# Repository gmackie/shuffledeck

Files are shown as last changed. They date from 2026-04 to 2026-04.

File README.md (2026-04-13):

# ShuffleDeck

Open-source automatic card shuffler for poker tables. Casino-grade randomization at a fraction of the cost.

## What is this?

A table-installed automatic shuffler that produces mathematically verified random output (9.2 riffle equivalents, indistinguishable from true uniform). Plus an RFID hole card reader and streaming overlay for live poker broadcasts.

## Product line

| Product | Price | Status |
|---|---|---|
| **ShuffleDeck Core** | ~$500 kit | CAD + firmware complete, pre-physical-build |
| **ShuffleDeck RFID** | ~$300 add-on | Prototype firmware, needs hardware validation |
| **ShuffleDeck Stream** | Free | Working demo overlay |

## Architecture

2-pass, 8-bin random FIFO shuffle. 52 cards are singulated by a friction roller, routed to one of 8 bins by a belt-driven selector, recombined, and shuffled again. The result is mathematically indistinguishable from a true uniform random permutation.

- **Shuffle time:** 30 seconds
- **Randomization:** ~9.2 riffle equivalents (7 is the classic Bayer-Diaconis benchmark)
- **Controller:** ESP32 with TMC2209 stepper drivers
- **Card support:** New KEM (plastic) and Bee (paper) poker cards
- **BOM cost:** ~$300

## Repository structure

```
sim/                        Shuffle quality simulator (Python)
cad/                        Parametric CAD (Build123d)
  constants.py              Shared dimensions and tolerances
  chassis/                  3-section printable base plate
  feeder/                   Hopper + singulation mechanism
  selector/                 Belt-driven card routing carriage
  bin_bank.py               8-bin FIFO storage
  recombine/                Pusher/elevator + squaring station
  output/                   Deck receiving tray
  renders/                  GLTF + STEP exports for rendering
firmware/
  shuffler/                 Production firmware (ESP32, 13-state machine)
  bakeoff-rig/              Feeder test bench instrument
  rfid-reader/              RFID card reader prototype
site/
  index.html                Landing page with 3D model viewer
  overlay.html              OBS streaming overlay
docs/plans/
  2026-04-09-...design.md   V1 design document
  datum-tolerance-budget.md Interface tolerance stackups
  bom.md                    Full bill of materials
  wiring-pinout.md          GPIO assignments and wiring guide
  print-guide.md            3D printing settings per part
  assembly-sequence.md      12-phase build instructions
  feeder-bakeoff.md         Feeder candidate test protocol
  market-research.md        Smart poker table market analysis
  motor-setup-lumen.md      Wiring guide for salvaged Lumen 3D printer motors
  rfid-felt-test.md         $19 RFID through-felt validation protocol
  preflight-checklist.md    First power-on safety and test sequence
```

## Quick start

### Run the shuffle quality simulator

```bash
python3 sim/shuffle_quality.py
```

### Export CAD models

```bash
uv venv .venv && source .venv/bin/activate
uv pip install build123d
cd cad && python export_all.py       # STEP + STL for all modules
cd cad && python render_images.py    # GLTF for 3D viewer
```

### Flash firmware

```bash
cd firmware/shuffler && pio run -t upload    # production shuffler
cd firmware/bakeoff-rig && pio run -t upload # feeder test bench
cd firmware/rfid-reader && pio run -t upload # RFID reader
```

### Preview the landing page

```bash
python3 -m http.server 8765
open http://localhost:8765/site/index.html
```

### Preview the streaming overlay

```bash
open http://localhost:8765/site/overlay.html
```
Demo mode activates automatically without RFID hardware connected.

## Build the shuffler

1. Order parts from [`docs/plans/bom.md`](docs/plans/bom.md) (~$300)
2. Print parts per [`docs/plans/print-guide.md`](docs/plans/print-guide.md)
3. Wire electronics per [`docs/plans/wiring-pinout.md`](docs/plans/wiring-pinout.md)
4. Assemble per [`docs/plans/assembly-sequence.md`](docs/plans/assembly-sequence.md)
5. Flash firmware and calibrate

## Design validation

The randomization architecture was validated by Monte Carlo simulation (10,000 trials) against 4 metrics:

| Metric | 2-pass 8-bin | True uniform | 7 riffles |
|---|---|---|---|
| Rising sequences | 26.08 ± 2.11 | 26.48 ± 2.10 | 24.96 ± 2.06 |
| Adjacency preserved | 1.45 | 0.98 | 1.15 |
| Mean displacement | 17.16 | 17.32 | 17.25 |
| Kendall tau | 651 | 663 | 658 |

Full results: [`docs/tests/shuffle-quality-results.txt`](docs/tests/shuffle-quality-results.txt)

## License

Open-source hardware and software. License TBD.

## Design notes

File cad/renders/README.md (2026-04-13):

# Card Shuffler — Render Assets

STEP files for marketing renders, generated by `render_setup.py`.

## Files

| File | Description |
|---|---|
| `assembly_full.step` | Complete assembly — all parts positioned in their correct locations |
| `assembly_exploded.step` | Exploded view — parts offset along Z axis for visual clarity |
| `feeder_detail.step` | Feeder module with Candidate A singulation mechanism |
| `bin_bank_detail.step` | 8-bin bank standalone |

## Generating

```bash
cd cad
python render_setup.py
```

Requires `build123d` (`pip install build123d`).

## Rendering Options

### FreeCAD (Raytracing)

1. Open FreeCAD >= 0.21
2. File > Import > select the `.step` file
3. Switch to the Render workbench (install via Addon Manager)
4. Create a render project (Cycles, LuxCore, or Appleseed backend)
5. Assign materials and set up 3-point lighting
6. Render at 2048x2048 or higher

### Blender (STEP Import)

1. Install [blender_step_importer](https://github.com/30350n/blender_step_importer) or CAD Sketcher addon
2. File > Import > STEP > select the file
3. Assembly imports as separate mesh objects — assign materials in Shader Editor
4. Use an HDRI environment for realistic lighting
5. Render with Cycles at 2048x2048+

**Suggested material palette:**
- Chassis: matte light aluminum
- Bin bank: semi-gloss dark gray
- Feeder / selector: accent blue or orange
- Output tray: same as chassis

### CadQuery Jupyter Viewer (Quick Preview)

```python
import cadquery as cq
from jupyter_cadquery import show
result = cq.importers.importStep("cad/renders/assembly_full.step")
show(result)
```

### OCP CAD Viewer (Build123d Native)

```python
from ocp_vscode import show
# Build parts using render_setup.py functions, then:
show(assembly)
```

## Recommended Camera Angles

### 3/4 Hero Shot (primary marketing image)
- **Camera:** (1200, -800, 600) mm
- **Look-at:** center of bin bank, approximately (400, 50, 30)
- Shows full machine: feeder, bin bank, and output tray in one frame

### Top-Down Overview
- **Camera:** (400, 50, 1000) mm
- **Look-at:** (400, 50, 0)
- Orthographic or long-focal-length perspective
- Shows the card flow path from feeder to output

### Feeder Detail (close-up)
- **Camera:** (80, -120, 100) mm
- **Look-at:** (50, 0, 30)
- Tight shot on singulation mechanism and feed rollers

### Bin Bank Detail
- **Camera:** (400, -200, 200) mm
- **Look-at:** center of bin bank
- Shows 8-bin array with funnel entries visible

### Exploded View (technical illustration)
- Use `assembly_exploded.step`
- **Camera:** (1200, -1000, 800) mm
- **Look-at:** center of assembly
- Shows layered construction: chassis, modules, selector on top

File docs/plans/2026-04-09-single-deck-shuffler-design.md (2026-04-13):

<!-- /autoplan restore point: /Users/mackieg/.gstack/projects/shuffle/main-nogit-autoplan-restore-20260410-142438.md -->
# Single-Deck Automatic Card Shuffler V1 Design

Date: 2026-04-09
Status: Validated design draft

## Summary

This document defines the V1 design for a DIY automatic single-deck poker card shuffler intended for reliable home or pro-am table use. V1 explicitly excludes guided cut-card insertion. The machine is designed as a standalone chassis that can later be adapted into a table-mounted installation with separate dealer-facing openings for the input hopper and output tray.

The chosen architecture prioritizes reliability over compact size or maximum speed:

- Single inclined input hopper
- Friction roller plus retard pad singulation
- 8-bin randomization core
- Two-pass shuffle process
- Separate output tray
- ESP32-based control system
- Standalone chassis sized for later table integration

## Locked Decisions

- Reliability-first design
- Two-pass random bin shuffle
- Friction roller plus retard pad feeder
- 8 storage bins
- ESP32 main controller
- Standalone enclosure dimensioned for future drop-in table integration
- No cut-card mechanism in V1

## Targets — 2026-04-10

Locked via user decision during autoplan execution. These are the numbers V1 ships against. If the feeder bakeoff or subsystem bench tests show any target is infeasible, escalate before silently relaxing.

| Target | Value | Source |
|---|---|---|
| **Primary user** | Pro-am / home poker night, degrades gracefully to home mode | User decision |
| **Shuffle quality** | ≥ 7 riffle-shuffle equivalents (Bayer-Diaconis) | Tier 0 sim validated 2-pass 8-bin FIFO at ~9.2 riffles |
| **Cycle time ceiling** | ≤ 30 s per deck, load-to-tray (pro-am mode); home mode may run slower | User decision |
| **BOM ceiling** | ≤ $500 (hardware only, excludes print plastic and labor) | User decision |
| **Supported deck envelope (V1)** | New KEM plastic + new Bee paper only | User decision |
| **Deferred to V2** | Worn decks, humidity-conditioned, warped (≥ 1 mm bow) | Out of V1 scope |
| **Jam rate** | ≤ 1 unrecovered jam per 500 decks across supported envelope | Test plan Tier 2 |
| **False-success rate** | 0 per 10,000 decks (hard gate) | Test plan Tier 2 |
| **Wear-part swap time** | ≤ 60 s, no re-calibration | Test plan Tier 1 |
| **Cycle time derivation** | 52 cards × 2 passes ÷ 30 s ≈ 104 singulations in ~20 s (leaves ~10 s for recombine + transport) → ~5 cards/s → ~120 mm/s feed speed for 63 mm cards | Arithmetic |

**Cycle time note:** 30 s is aggressive for friction+retard singulation at ~120 mm/s feed speed. This sits above the "laser printer sweet spot" of ~80 mm/s. The feeder bakeoff Phase 2 DOE must include a 120 mm/s point and the winner must pass the BH (humidity) deck at that speed with margin — except BH is out of V1 envelope, so the bakeoff uses BN (new Bee paper) as the worst case instead. If 120 mm/s fails the new Bee paper test cleanly, the options are: (a) relax cycle time to 40 s and run at 80 mm/s, (b) overlap passes (start pass 2 singulation while pass 1 recombine finishes), or (c) switch candidate to escapement/kicker which tolerate higher speeds at the cost of parts count. Decision deferred until bakeoff data exists.

**BOM headroom ($500 vs ~$250 friction+retard BOM):** the extra ~$250 buys: a full vacuum pickup candidate in the bakeoff, a small OLED for diagnostics, better sensors (e.g. Omron B5W-LB2101 over bare TCRT5000), a second ESP32 for logging without interfering with the control loop, and one surprise. Use it.

## Product Goals

- Accept one full 52-card deck in a single input hopper
- Shuffle automatically without manual deck splitting
- Deliver the final shuffled deck to a separate output tray
- Operate conservatively enough to minimize jams and double-feeds
- Detect card-count mismatches and report failure rather than claim success
- Keep all wear parts and jam-clearance points serviceable

## System Architecture

The machine is divided into modular assemblies:

1. Feeder module
2. Selector module
3. Bin bank
4. Recombine module
5. Output module
6. Electronics bay

Cards are loaded into a slightly inclined hopper. The bottom card is singulated by a driven friction roller working against a retard pad. After sensor confirmation, the card enters a selector path and is routed into one of 8 storage bins chosen by the controller. Once all cards are distributed, the machine recombines the bins in a controlled sequence into a temporary stack. That stack is then run through the same process a second time. After the second recombination, the finished deck is delivered to the output tray.

The chassis should remain physically generous in V1. The design should prefer larger clearances, easier access, and slower speeds over compactness.

## Mechanical Design

### Feeder Module

The feeder is the highest-risk subsystem and should be designed for tuning and replacement:

- Inclined hopper with adjustable side rails
- Spring-loaded rear backstop
- Bottom exit throat sized for standard poker cards
- Driven friction roller with replaceable O-ring or silicone sleeve
- Replaceable retard pad opposing the second card
- Adjustable nip and feed pressure
- Two sensors near the feed throat for motion confirmation and timing

The feeder should run conservatively. The primary objective is stable single-card release, not throughput.

### Selector Module

The selector receives each singulated card and routes it into one of 8 bins:

- Narrow guided card path after the feeder
- Stepper-driven diverter or gate
- Fixed, repeatable routing positions
- Sensor checkpoint at the selector throat

The selector must be accurate enough that bin entry errors are rare even with slightly warped or worn cards.

### Bin Bank

The 8 bins should be easy to clear and tolerant of alignment variation:

- Vertical or slightly inclined storage bins
- Large entry funnels
- Removable access covers
- Smooth low-friction internal surfaces
- Geometry that keeps partial stacks square enough for recombination

### Recombine Module

Recombination should be controlled rather than passive:

- Retrieve cards or partial stacks from bins in deterministic order
- Guide them into a temporary stack with side constraint
- Feed the temporary stack back into pass two
- Repeat the same process after pass two into the final output tray

Free-fall stacking should be avoided where it can produce skewed or collapsed stacks.

### Output Module

The output tray should square the deck as it lands:

- Separate tray physically distinct from input hopper
- Side guides or light compression geometry
- Dealer-friendly access
- Layout compatible with a future table cutout

## Controls and Electronics

### Controller

- ESP32 DevKit as the main controller

Reasons:

- Sufficient control capability for state-machine firmware
- Better expansion options than a smaller Arduino board
- Easy future support for logging, diagnostics, or small display upgrades

### Motors

Recommended V1 direction:

- Stepper motors where position matters
- Low-speed geared motor or stepper for the feeder
- TMC2208 or TMC2209 drivers for steppers

Likely motor roles:

- Selector positioning
- Recombine gate or pickup motion
- Optional elevator or output alignment motion
- Feeder drive

### Sensors

Use sensors at choke points rather than saturating the machine with them:

- Hopper/feed exit sensor
- Post-singulation confirmation sensor
- Selector throat transit sensor
- Recombine entry or pickup confirmation sensor
- Recombine exit sensor
- Final output count checkpoint

Total expected sensor count: approximately 5 to 7.

### User Interface

Minimal V1 UI:

- `Shuffle` button
- `Stop/Clear Jam` button
- Status LEDs
- Optional buzzer

Service mode should be available for:

- Jog feeder
- Jog selector
- Jog recombine mechanism
- Run sensor tests

## Firmware Design

Firmware should be implemented as an explicit state machine:

- `idle`
- `feeding_pass_1`
- `recombine_1`
- `feeding_pass_2`
- `recombine_2`
- `complete`
- `jam_recovery`
- `service_mode`

The machine should maintain expected card counts throughout the cycle. On sensor timing failure or count mismatch, it should stop, identify the failing segment, reverse only the affected mechanism a short distance, and retry a limited number of times before entering a fault state.

The controller should never report a successful shuffle unless the end-to-end count matches 52 cards.

## Randomization Strategy

V1 uses two-pass random bin distribution:

- Pass 1: each singulated card is assigned to one of 8 bins using controller-generated randomness
- Recombine bins into a temporary stack
- Pass 2: run the temporary stack through the same 8-bin process again
- Recombine into final output deck

This approach offers significantly better mixing than a single-pass system while remaining much simpler than slot-rack or carousel architectures.

## Recommended Materials and Parts

- PETG for structural printed parts
- TPU only where flexible contact surfaces are needed
- ESP32 DevKit
- 2 to 4 NEMA17 stepper motors
- 1 low-speed geared feeder motor or equivalent stepper
- TMC2208 or TMC2209 drivers
- 12V power supply
- 5V buck converter
- IR sensors
- O-rings or silicone sleeves for feed rollers
- Replaceable retard pad material
- Common bearings such as 608-class where appropriate
- Springs, shoulder bolts, heat-set inserts, wiring, connectors

## Primary Failure Modes to Design Around

- Double-feed at the hopper
- Card skew or nose-dive at the feed throat
- Selector misrouting
- Bin entry jams
- Poor partial-stack geometry during recombination
- Final deck squaring issues in the output tray
- False-success reporting after a count mismatch
- Service procedures that require excessive disassembly

Each jam-prone region should be accessible without tearing down the entire machine.

## Integration Strategy

V1 should be built as a standalone tabletop unit first. The enclosure dimensions should anticipate future conversion into a table-installed module, but the mechanics should not be compromised for under-table constraints yet. The table integration phase should primarily involve mounting, trim, and access design rather than a full mechanical redesign.

## Next Steps

1. Produce a dimensioned subsystem layout for feeder, selector, bins, recombine path, and output tray.
2. Choose exact feeder motor strategy: geared DC motor with feedback or stepper.
3. Define bin selector mechanism in CAD.
4. Build a feeder-only prototype and tune singulation reliability.
5. Add sensor instrumentation and collect timing data.
6. Prototype one-pass bin routing before committing to full two-pass mechanics.
7. Build the full bin bank and recombine path.
8. Implement firmware state machine and jam recovery.
9. Run repeated 52-card validation testing across multiple deck conditions.

## Open Questions

- Final target footprint for the tabletop chassis
- Exact feeder drive choice
- Specific recombine mechanism geometry
- Whether output squaring needs passive guides only or a light active constraint

---

<!-- AUTOPLAN REVIEW BELOW — generated 2026-04-10 -->

# /autoplan Review — Phase 1: CEO

## Phase 1.0 — Prior Art Map (what already exists)

Sub-problem to existing solution:

| Sub-problem | Commercial / prior art | Status |
|---|---|---|
| Home/pro-am shuffler | Shuffle Tech ST-1000 (~$849, 1-2 decks), DeckMATE clones (~$40-120 AliExpress), Shuffle Master used casino units | Covered at multiple price points |
| Junk-tier battery auto-shufflers | Home Depot / Amazon ~$11-15 | Unreliable but solves single-deck for a fiver |
| DIY open projects | Hackaday entries, Instructables, a few YouTube builds | Exist but none dominant; no de facto open platform |
| Friction-roller singulation | Every desktop printer ever | Well-characterized, wear-replacement norm is known |
| Retard pad tuning | Canon / HP service manuals, cheap OEM pads | Characterized |
| 52-slot placement shufflers | Casino-grade multi-deck (ShuffleMaster DeckMate 2) | Existence proof that "one pass, one card per slot" works at scale |
| Randomness quality measurement | Bayer-Diaconis 7-riffle result, rising-sequence test, TV-distance-from-uniform | Standard stats; 30-line Python sim is possible |
| ESP32 firmware state machine | Arduino/ESP32 steppers+TMC2209, tons of reference code | Commodity |

**Key implication:** there is no moat unless this plan targets a specific wedge (open/inspectable/repairable, custom shuffle modes, table-integrated, quiet, sub-$300 BOM). The plan does not state its wedge. See Premise Gate.

## Phase 1.0A — Premise Challenge

Premises stated as locked, and their current evidence:

| # | Premise | Stated | Evidence backing it | Status |
|---|---|---|---|---|
| P1 | Two-pass 8-bin randomization produces acceptable mixing | Locked | None — no simulation, no combinatorics, no target metric | **UNPROVEN** |
| P2 | 8 bins is the right count | Locked | None — not compared to 6, 10, 12, 16 | **ARBITRARY** |
| P3 | Two passes is the right count | Locked | None — not compared to 1-pass / 3-pass | **ARBITRARY** |
| P4 | Friction roller + retard pad is the right singulator | Locked | Familiarity ("printers do it") — no bakeoff | **ASSUMED** |
| P5 | "Reliability-first over compact/fast" matches real user tolerance | Locked | No user research; no cycle-time or size ceiling stated | **ASSUMED** |
| P6 | Standalone chassis can be sized for future table integration without compromise | Locked | No analysis of the dual-constraint trap | **LIKELY WRONG** |
| P7 | ESP32 is sufficient | Locked | True — this one is fine | **OK** |
| P8 | DIY is worth building at all vs commercial alternatives | Unstated | None — no build-vs-buy analysis | **MISSING** |
| P9 | No cut-card in V1 is acceptable scope | Locked | Explicitly scoped out | **OK** |

## Phase 1.0B — Randomization Quality: the core math

Both CEO voices independently computed that **two-pass 8-bin is not a good shuffle**:

- **Radix sort framing (Codex):** two passes into 8 bins is structurally a stable 2-digit base-8 sort. 52 cards distribute across 64 possible (bin₁, bin₂) buckets. Expected collisions: ~20.7 unordered pairs whose relative order is preserved by construction. A real shuffle has ~0 such preserved pairs.
- **Adjacency bias (Claude):** cards adjacent in the input hopper have P=1/8 of landing in the same bin with preserved order each pass. After two passes, P(still adjacent in output) ≈ 1/64 ≈ 1.5%. Across 51 adjacency pairs, expected ~0.8 preserved adjacencies per deck. Detectable. Exploitable.
- **Bits-of-entropy framing (Claude):** log₂(8)=3 bits per card per pass → ~6 bits over two passes. That's roughly equivalent to **2-3 riffle shuffles**, far below the Bayer-Diaconis 7-riffle benchmark for a uniformly mixed deck.

**Verdict:** the entire product's reason to exist rests on an unvalidated, almost certainly inadequate randomization strategy. This is the headline finding.

## Phase 1.0C — Implementation Alternatives (3-approach Pugh)

| Dimension | A) Two-pass 8-bin (current plan) | B) Slot-rack 52-slot one-pass | C) Single-pass 16+ bin |
|---|---|---|---|
| Mixing quality | ~2-3 riffle equivalents; preserved-pair bias | Provably uniform (each slot holds 1 card in random assignment) | ~3-4 bits/card, single pass; better than A if bins ≥ 16 |
| Mechanisms | Feeder + selector + 8-bin + recombine ×2 | Feeder + XY or linear slot positioner | Feeder + selector + 16-bin + recombine |
| Jam surface area | 2 feeds, 2 recombines per shuffle | 1 feed, 1 placement, 1 recombine | 1 feed, 1 recombine |
| Cycle time budget | 52 cards × 2 passes = 104 feed events | 52 cards × 1 pass = 52 placement events | 52 cards × 1 pass = 52 feed events |
| State machine complexity | 8 states | 4-5 states | 4-5 states |
| Dismissed in plan? | No (current pick) | Yes, without quantitative argument | Not mentioned |
| Deterministic count verification | Possible but hard (partial stacks) | Trivial (each slot = 1 card) | Same as A |

**Neither voice recommends A.** Codex recommends a real Pugh matrix including drum/carousel, pick-and-place, mechanical riffle. Claude recommends prototyping B in parallel with the feeder and being willing to abandon the 8-bin architecture.

## Phase 1.0D — Dream State Diagram

```
CURRENT STATE           THIS PLAN (V1 as written)      12-MONTH IDEAL
──────────────           ─────────────────────────       ─────────────────────
No machine.              Standalone unit that           Open-source, repairable,
Manual shuffling.        sometimes jams and              table-integrated shuffler
Design doc only.         produces ~2-3 riffle-          with provably uniform
                         equivalent mixing.              output, ≤1 jam/500 decks,
                         No targets. No metric.          ≤25s cycle, <$300 BOM,
                         No wedge vs commercial.         published test harness.
```

**Delta from plan to ideal:** the plan does not name the wedge, does not define targets, and does not validate its randomization. V1 as written delivers an inferior version of a $40 DeckMATE clone.

## Phase 1.0E — Temporal Interrogation (hour-by-hour regret)

- **Hour 1 after feeder prototype built:** "I wish I'd bought the cheap Canon retard pad instead of casting my own."
- **Hour 6 after bin selector integrated:** "I can't change bin count without reprinting the frame. I should have made the bin bank modular."
- **Hour 12 after first full shuffle cycle:** "The output does not look random. I should have written the test harness first."
- **Week 2 after randomness measured:** "Two passes is not enough. I'm going to add a third pass. Wait — I could have picked slot-rack."
- **Month 2:** "I should have done the build-vs-buy analysis in week 1."

## Phase 1.0F — Mode Selection

Mode: **SELECTIVE EXPANSION** — the plan is structurally incomplete (missing targets, missing randomness validation, missing build-vs-buy, missing wedge) but the locked decisions are salvageable IF the user confirms the premises after seeing the evidence.

## Phase 1.0.5 — Dual Voices Consensus

### CEO DUAL VOICES — CONSENSUS TABLE

| Dimension | Claude subagent | Codex | Consensus |
|---|---|---|---|
| 1. Premises valid? | NO — core randomization math unchecked | NO — radix sort framing makes bias structural | **DISAGREE with plan → both agree it's wrong** |
| 2. Right problem to solve? | NO — no build-vs-buy, no JTBD lock | NO — no 10x wedge stated | **DISAGREE with plan** |
| 3. Scope calibration correct? | NO — dual-constraint chassis trap; scope leaking to table | NO — dual-optimization trap flagged | **DISAGREE with plan** |
| 4. Alternatives sufficiently explored? | NO — slot-rack dismissed in one sentence | NO — no Pugh matrix; mechanical riffle ignored | **DISAGREE with plan** |
| 5. Competitive/market risks covered? | NO — DS-1 / clones not named | NO — ST-1000 at $849, junk-tier at $11-15 | **DISAGREE with plan** |
| 6. 6-month trajectory sound? | NO — 3 explicit regret scenarios | NO — 3 explicit regret scenarios | **DISAGREE with plan** |

**Result: 0/6 CONFIRMED. Both models independently concluded every strategic dimension of the plan has a gap.** This is an unusually strong consensus and is treated as a User Challenge at the final gate.

## Phase 1 — Error & Rescue Registry

| Error class | Source | Rescue | Gap |
|---|---|---|---|
| Double-feed at hopper | Feeder module | Sensor timing → retry with reverse-jog | Plan has no threshold or retry count |
| Card skew at throat | Feeder module | Not specified | **GAP** |
| Selector misroute | Selector | Not specified | **GAP** |
| Bin entry jam | Bin bank | Removable access covers | No firmware-level detection described |
| Recombine stack collapse | Recombine | "Side constraint" | **GAP — mechanism unspecified** |
| Sensor dropout | Any sensor | Not specified | **GAP** |
| Count mismatch at output | Firmware | Report failure, do not claim success | OK — this one is covered |
| False-success report | Firmware | End-to-end count check | OK — this one is covered |

## Phase 1 — Failure Modes Registry (strategic level)

| Mode | Probability | Impact | Mitigation in plan | Critical gap? |
|---|---|---|---|---|
| Randomization quality inadequate | **HIGH** (both voices calculated it) | Product has no reason to exist | None | **YES** |
| Feeder bakeoff not done | **HIGH** | Wrong singulator chosen, affects everything downstream | None | **YES** |
| Chassis envelope frozen before subsystem proofs | **HIGH** | Rework after feeder tuning | None | **YES** |
| No cycle-time budget | **HIGH** | Feeder tuned for wrong speed regime | None | **YES** |
| No MTBF/jam-rate target | **MEDIUM** | Can't tell when V1 is "done" | None | **YES** |
| Commercial alternative does the job for $40-150 | **HIGH** | Project has no wedge | None | **YES** |
| Slot-rack is actually simpler and uniform | **MEDIUM** | Abandon 8-bin months into build | One-sentence dismissal | **YES** |

## Phase 1 — "NOT in scope" (derived from this review)

Should be explicitly out of V1 to keep it shippable:

- Cut-card mechanism (already scoped out — OK)
- Table-integrated form factor (should be deferred entirely — dual-constraint trap)
- Multi-deck handling
- Network / logging / display beyond minimal LEDs (but see SSD1306 suggestion below)
- Auto-calibration of feeder nip / pressure
- Custom shuffle modes

## Phase 1 — "What already exists" (derived)

Sub-problems with existing solutions the builder should buy, not build:

- Retard pads → Canon/HP OEM, ~$5, characterized wear profile
- IR break-beam sensors → Adafruit / generic, ~$2 each
- TMC2209 driver silent stepper → ~$8
- Shuffle-quality test harness → 30-line Python simulation using `rising_sequence_count` or TV-distance metric
- State-machine firmware skeleton → countless ESP32 examples
- Build-vs-buy baseline → just buy a Shuffle Tech DS-1 used for teardown at ~$150

## Phase 1 — Completion Summary

| Section | Finding | Severity |
|---|---|---|
| Prior art map | No wedge stated; commercial alternatives not argued against | Critical |
| Premise P1 (2-pass 8-bin quality) | Both voices computed it is inadequate (~2-3 riffles, preserved pairs by construction) | **CRITICAL** |
| Premise P2 (8 bins) | Arbitrary, no trade study | High |
| Premise P3 (two passes) | Arbitrary, no trade study | High |
| Premise P4 (friction + retard) | No bakeoff, chosen by familiarity | High |
| Premise P5 (reliability-first) | Unfalsifiable without numbers | High |
| Premise P6 (dual-constraint chassis) | Classic dual-optimization trap | High |
| Premise P8 (build-vs-buy) | Missing entirely | Critical |
| Alternatives table | Missing; slot-rack and drum/carousel unexamined | Critical |
| Targets section | Missing (cost, cycle time, jam rate, quality metric) | Critical |
| Error & Rescue Registry | Multiple gaps for skew, misroute, sensor dropout, recombine collapse | High |
| 6-month regrets | 3+ explicit scenarios from both voices | Critical |
| Dream state delta | Plan as written underperforms $40 commercial clones on quality and $11 clones on cost | Critical |

---

**Phase 1 complete.** Codex: 20 concerns (10 critical, 9 high, 2 medium). Claude subagent: 18 findings (5 critical, 9 high, 4 medium). Consensus: 0/6 confirmed, 6 disagreements all aligned → surfaced at final gate as a User Challenge. Premise gate reached.

### Phase 1 — Premise Gate Decision

User selected: **"Validate first, then lock architecture."**

Effect on the plan:
- Premises P1 (2-pass 8-bin quality), P2 (8 bins), P3 (two passes), P4 (friction+retard feeder) are **UNLOCKED pending evidence**.
- Before any CAD work, the plan now requires:
  1. A Python simulation comparing ≥3 architectures (2-pass 8-bin, slot-rack 52, 1-pass 16-bin) on a real mixing-quality metric (rising-sequence count, TV-distance from uniform, or riffle-shuffle equivalence).
  2. A Targets section with BOM ceiling, cycle time ceiling, jam rate target, shuffle-quality threshold, card-envelope definition.
  3. A feeder-separator bakeoff comparing friction+retard against at least one alternative (escapement, single-roller vacuum, kicker) on measured double-feed rate.
- Table-integration scope is **deferred entirely to V2** (per the dual-constraint trap finding).
- Premise P8 (build-vs-buy) requires a one-paragraph wedge statement before the plan is considered ready for implementation.

---

# /autoplan Review — Phase 2: Design

**SKIPPED.** No software UI surface. Physical ergonomics belong in the mechanical design review, not the screen-design review skill.

---

# /autoplan Review — Phase 3: Engineering

Focused on: (a) the validation strategy, since the architecture is TBD, (b) the feeder as an architecture-independent subsystem, (c) the firmware state machine pattern, (d) the test/validation plan.

## Phase 3.0 — Scope Challenge (adapted for hardware)

No source code exists yet — this is a pure green-field hardware plan. Scope challenge is framed as: "what do the existing reference designs already solve that this plan re-invents unnecessarily?"

- **Canon / HP retard pads:** characterized wear curves, ~$5/unit, bolt-in form factor.
- **Printer feeder geometry (throat + sensor) reference designs:** multiple public teardowns; the plan can copy throat spacing, nip force, and lead-in chamfer dimensions instead of deriving from scratch.
- **ESP32 + TMC2209 stepper firmware:** countless reference codebases; state machine skeleton is not novel work.
- **IR break-beam placement patterns:** standard printer reference designs apply directly.

None of these are touched in the plan. Each can be bought as a known-good component rather than derived from first principles.

## Phase 3.1 — Architecture (mechanical + firmware)

### Mechanical module block diagram (consensus from both voices)

```
  [INPUT HOPPER]
        |
        v
  +------------+       sensor A (break-beam, throat enter)
  |  FEEDER    |  --> sensor B (break-beam, post-singulate)
  +------------+
        |
        v
  +------------+       sensor C (break-beam, selector throat)
  |  SELECTOR  |
  +------------+
        | routed to one of N bins (N TBD pending Tier 0 sim)
        v
  +----+----+----+----+----+----+----+----+
  | b1 | b2 | b3 | b4 | b5 | b6 | b7 | b8 |    BIN BANK
  +----+----+----+----+----+----+----+----+
         | deterministic pickup order
         v
  +-------------+      sensor D (pickup confirm)
  | RECOMBINE   | --> sensor E (recombine exit)
  +-------------+
         |
         +--> pass 1: back to FEEDER hopper reload (if multi-pass arch)
         +--> final: to OUTPUT
                 |
                 v
            +------------+       sensor F (output count)
            |   OUTPUT   |
            +------------+

  [ELECTRONICS BAY]  ESP32 + N×TMC2209 + feeder drv + PSU
```

### Architecture findings

| # | Finding | Sev | Fix |
|---|---|---|---|
| A1 | No datum / tolerance budget across module boundaries | Critical | Define hard datums, kinematic mounts, per-handoff pitch/yaw/height budget |
| A2 | Feeder → selector handoff is "narrow guided path" — warped cards nose-dive | High | Captive bridge with continuous lower support, lead-in chamfers sized from card envelope |
| A3 | Recombine module is hand-waved despite being second-highest risk | Critical | Pick ONE extraction concept now (compliant pickup head, belt strip, roller lift) and prototype before full CAD |
| A4 | Bin-bank / selector coupling: selector error and bin funnel offset are indistinguishable to firmware | Medium | Bin funnels 2-3x wider than selector positional error so selector owns tolerance alone |
| A5 | Stack squareness budget undefined at recombine → pass 2 handoff | High | Spec max skew (e.g. ≤1 mm across 52 cards), add squaring step (tap plate or jogger) |
| A6 | Card envelope undefined → throat, funnel, bin geometry have no design basis | Critical | Requirements table: card width/length/thickness, 52-card stack height, bow/curl, finish class, qualified deck set |

### Firmware state machine findings

Current plan: 8 states (`idle`, `feeding_pass_1`, `recombine_1`, `feeding_pass_2`, `recombine_2`, `complete`, `jam_recovery`, `service_mode`).

| # | Finding | Sev | Fix |
|---|---|---|---|
| S1 | Missing `boot_selftest` / `homing` / `calibrate` / `fault_latched` | High | Add boot → selftest → homing → idle path; refuse idle on any fault |
| S2 | `jam_recovery` is a substate family, not a state | Critical | Split into `fault_feeder`, `fault_selector`, `fault_recombine`, `fault_count` with bounded per-mechanism retry |
| S3 | Missing `paused` distinct from fault (user-pressed Stop ≠ jam) | Medium | Add `paused` with resume/abort transitions |
| S4 | Abort-mid-cycle, power-loss recovery, sensor-fail behavior unspecified | High | Define safe-stop rules, retained context, resume-vs-scrap criteria |
| S5 | End-to-end count=52 is insufficient invariant | Critical | Per-pass invariants: feeder_exits == selector_entries == sum(bin_counts); recombine_out == sum(bin_counts) before pass 2 or success |
| S6 | Brownout during shuffle loses count state | High | On brownout IRQ, write pass + bin counts to ESP32 NVS. On reboot → `fault_power`; never auto-resume; require operator clear |

## Phase 3.2 — Feeder Subsystem

| # | Finding | Sev | Fix |
|---|---|---|---|
| F1 | No nip-pressure tuning protocol — "adjustable" with no target or measurement | Critical | Gram-force gauge or calibrated spring; target range (150-300 gf); log before every test run; reference-gauge + locked calibration position |
| F2 | Two throat sensors with no defined events | High | Sensor A = `card_started` (leading edge at roller exit); B = `card_singulated` (leading edge post-singulate). A→B interval validates single-card transit; B→nextA validates spacing; A-still-blocked-past-threshold = double-feed fault |
| F3 | No sensor sample rate / polling spec | High | At 200 mm/s transit + 3 mm IR beam, leading edge crosses in ~15 ms. Require HW interrupt or ≥1 kHz poll. Document worst-case transit, require ≥10x sample rate |
| F4 | No wear curve / swap-time target | High | Life-test roller sleeve + retard pad; singulation error vs cycles; require ≤60 s swap with no re-shim |
| F5 | Throat event classification for double-feed / skew / stall / bounce-back not specified | Critical | Sensor spacing + edge sequence rules; thickness discriminator OR dual-zone measurement; 100% classification on induced events |
| F6 | No bakeoff — friction+retard chosen on familiarity | Critical | DOE bakeoff: roller durometer × retard pad material × nip force × feed speed across fixed deck matrix before freezing geometry |

## Phase 3.3 — Test / Validation Plan (MANDATORY SECTION)

**Full test plan written to disk:** `/Users/mackieg/.gstack/projects/shuffle/mackieg-main-nogit-test-plan-20260410-142438.md`

The test plan defines three tiers:

1. **Tier 0 (pre-CAD, pure Python):** architecture shuffle-quality simulator comparing ≥3 candidate architectures on rising-sequence, TV-distance, adjacency-preservation, and riffle-shuffle-equivalence metrics. Gate: ≥7 riffle equivalence before any CAD.
2. **Tier 1 (subsystem bench rigs):** feeder bakeoff, wear life, sensor timing, selector positional repeatability, recombine pickup/handoff.
3. **Tier 2 (full system):** bring-up, per-pass invariant injection, jam recovery per segment, brownout recovery, 1500-deck MTBF soak across 6 deck conditions, physical randomness validation against Python model.

### Test Diagram — codepath / event → test → gap status

| Codepath / Event | Test that would catch failure | Gap in current plan? |
|---|---|---|
| Feeder singulate | Feed-only rig, 500 cards, nip-force log | **GAP** |
| Double-feed detection | Inject stuck cards, expect fault | **GAP** |
| Skew detection | Feed warped card, expect fault or recovery | **GAP** |
| Throat sensor timing | Logic analyzer on sensor pins during feed | **GAP** |
| Selector position repeatability | 1000 moves/bin, dial indicator | **GAP** |
| Selector misroute | Force off-by-one step, expect bin-drop sensor fault | **GAP (no bin sensor)** |
| Bin drop confirm | Per-bin drop sensor toggles on every card | **GAP (sensor missing)** |
| Recombine pickup | Partial-stack pickup, 100 cycles/bin | **GAP** |
| Recombine squareness | Feeler gauge on recombined stack | **GAP** |
| Per-pass invariants | Inject missed edge, expect mismatch fault | **GAP** |
| Pass-1 → Pass-2 handoff | 52 in / 52 out, 500 runs | Partial |
| Count verify | Remove card mid-run, expect fault | **GAP** |
| Randomization quality | Python harness + physical validation | **GAP — critical** |
| MTBF / jam rate | 1500-deck soak across 6 deck conditions | **GAP — critical** |
| Brownout recovery | Kill 12V mid-shuffle | **GAP** |
| Sensor dropout | Disconnect sensor, expect self-test fail | **GAP** |
| Wear-part swap time | Stopwatch change-out, ≤60 s | **GAP** |
| Boot self-test | Power-on blocked-path test | **GAP** |
| Thermal soak | 30 min continuous, log driver temps | **GAP** |

**Of 19 critical codepaths, 18 have no defined test.** The test plan is functionally empty in the current doc.

## Phase 3.4 — Sensor Strategy

| # | Finding | Sev | Fix |
|---|---|---|---|
| SE1 | No bin-drop confirmation sensor | High | Either per-bin reflective, shared moving sensor on selector head, OR single beam across all N bin entries that each card interrupts on the way in |
| SE2 | Break-beam vs reflective not assigned per location | Medium | Throat + selector transit + count checkpoint = break-beam (edge-accurate). Bin-presence + output-tray = reflective (presence only). Homing = mechanical / Hall switch |
| SE3 | EMI from stepper drivers + 12V bus not addressed | High | Separate analog 3.3V rail for IR receivers; ferrite on stepper power leads; twisted-pair sensor wiring; 100 nF at receiver; star ground at PSU |
| SE4 | No sensor-dropout detection | High | Boot self-test: each sensor must register both states via test card or flag. During run: expect each sensor to toggle within every pass; sensor that never toggles for >N cards = dead → fault |

## Phase 3.5 — Power / BOM

| # | Finding | Sev | Fix |
|---|---|---|---|
| P1 | PSU not sized | High | 4× NEMA17 @ 0.8A + feeder + ESP32 + sensors ≈ 4-5 A peak @ 12V with 2-3x inrush. Spec 12V / 8A min (Meanwell LRS-100-12 or equiv), 470 µF bulk near driver bank, staggered enable to avoid simultaneous inrush |
| P2 | TMC2209 thermals unaddressed | Medium | At 1 A RMS × 4 active drivers ≈ 4 W total. Add heatsinks + 40 mm 12V fan on driver bank; reduce IRUN, raise IHOLD only during holds |
| P3 | Worst-case current budget not closed | High | Calculate: all steppers + feeder motor + ESP32 logic + sensors + buck losses; compare against PSU rating with 30% margin |
| P4 | 5V buck not sized | Medium | ESP32 peaks at ~500 mA; sensors + logic ~100 mA; pick 5V/2A minimum |

## Phase 3.6 — Serviceability

| # | Finding | Sev | Fix |
|---|---|---|---|
| SV1 | Jam-clearance access not verified against layout | High | Red-team the card path, mark every jam-prone zone, verify each is reachable by removing ≤1 panel. Gate CAD review on this |
| SV2 | No calibration procedure documented | High | Per-build calibration artifact: selector zero positions, feeder nip force, sensor thresholds, retard pad angle. Store in NVS. Printable via service mode |
| SV3 | No diagnostic surface beyond LEDs + buzzer | High | Add $3 SSD1306 128×64 I²C OLED. Shows state, last fault code, sensor live view in service mode. Not scope creep — it's the diff between "tune it until it works" and "engineered" |
| SV4 | "Removable access covers" may disturb alignment | Medium | Jam-clear doors must be tool-less AND non-datum; locating features never touched during service |

## Phase 3.7 — Security

N/A. Unconnected local device, no attack surface beyond physical access.

## Phase 3.0.5 — Dual Voices Consensus

### ENG DUAL VOICES — CONSENSUS TABLE

| Dimension | Claude subagent | Codex | Consensus |
|---|---|---|---|
| 1. Architecture sound? | Modular split OK but recombine handoff unmodeled; `jam_recovery` is a family | Module split coherent but no datum/tolerance budget; feeder→selector handoff is the warp trap; recombine hand-waved | **DISAGREE with plan** (converges) |
| 2. Test coverage sufficient? | 16/18 codepaths have no test; randomness + MTBF both missing | 15-item test matrix all marked "missing" or "partial" | **DISAGREE with plan** (strong) |
| 3. Performance risks addressed? | No cycle time budget; no sensor polling spec | No ms timing budgets per segment | **DISAGREE with plan** |
| 4. Security threats covered? | N/A | N/A | **CONFIRMED N/A** |
| 5. Error paths handled? | `jam_recovery` too coarse; no per-pass invariants; no brownout recovery | Same; also abort-mid-cycle, sensor-fail, power-loss unspecified | **DISAGREE with plan** (strong) |
| 6. Deployment risk manageable? | Feeder bakeoff absent; chassis envelope frozen too early; calibration procedure absent | Same; also no card envelope, no deck condition matrix | **DISAGREE with plan** |

**Result: 1/6 CONFIRMED (security N/A), 5/6 DISAGREE with plan with both models converging on the same gaps.** No model-to-model disagreements — both reviewers independently identified the same engineering blind spots.

## Phase 3 — Failure Modes Registry (engineering level)

| Mode | Probability | Impact | Mitigation in plan | Critical gap? |
|---|---|---|---|---|
| Feeder double-feed undetected | Medium | False success | Throat sensors (no classification rules) | **YES** |
| Feeder wear → doubles over time | High | Drift failure | "Replaceable" but no life test | **YES** |
| Selector misroute | Medium | Count mismatch | Sensor at selector throat (but no bin-drop sensor) | **YES** |
| Recombine stack telescope | Medium | Pickup failure | "Side constraint" hand-wave | **YES** |
| Per-pass count drift | Low-medium | False success if end-to-end is only invariant | End-to-end only | **YES** |
| Brownout mid-shuffle | Low | Partial state / false resume | Unspecified | **YES** |
| EMI false-trigger sensor | Medium | Phantom card events | Unspecified | **YES** |
| TMC2209 thermal shutdown | Medium | Mid-run failure | Unspecified | **YES** |
| Sensor dropout (dead sensor reading "clear") | Low | Phantom success | Unspecified | **YES** |
| Jam in non-accessible location | Medium | Required full disassembly | "Accessible zones" stated but not verified | **YES** |

## Phase 3 — Completion Summary

| Section | Finding count | Critical | High | Medium |
|---|---|---|---|---|
| Architecture (mech + firmware) | 12 | 4 | 6 | 2 |
| Feeder | 6 | 3 | 3 | 0 |
| Test plan | 19 (gap matrix) | 2 | 15 | 2 |
| Sensors | 4 | 0 | 3 | 1 |
| Power / BOM | 4 | 0 | 3 | 1 |
| Serviceability | 4 | 0 | 3 | 1 |
| Security | 0 (N/A) | — | — | — |
| **TOTAL** | **49** | **9** | **33** | **7** |

**Phase 3 complete.** Codex: 20 findings (8 critical, 11 high, 1 medium). Claude subagent: 25 findings (3 critical, 14 high, 8 medium). Consensus: 1/6 confirmed (security N/A), 5/6 DISAGREE-with-plan with models converging. Zero model-to-model disagreements. Passing to Phase 4 (Final Approval Gate).

---

# /autoplan Review — Phase 3.5: DX Review

**SKIPPED.** No developer-user scope. End user is a dealer/host operating a finished hardware product, not a developer integrating a library or SDK. Firmware development happens internally and is covered by the engineering review.

---

# /autoplan Review — Phase 4: Final Approval Gate

**Status: APPROVED 2026-04-10.**

User accepted both user challenges and all auto-decided engineering additions. Effective plan deltas from original:

1. **Premises P1-P4 unlocked pending evidence.** Architecture (2-pass 8-bin vs slot-rack vs 1-pass N-bin), bin count, pass count, and feeder separator are all TBD until Tier 0 simulation + feeder bakeoff complete.
2. **Table-integration scope deferred entirely to V2.** V1 is a benchtop unit with no dual-constraint footprint requirements.
3. **SSD1306 128×64 I²C OLED added to V1 UI.** Diagnostic surface is now mandatory.
4. **Bin-drop sensor coverage is now a hard requirement.** Either per-bin reflective, shared moving sensor on selector head, or single beam across all bin entries.
5. **Per-pass count invariants required** (feeder_exits == selector_entries == sum(bin_counts)). End-to-end-only is insufficient.
6. **Firmware state machine expanded.** Add `boot_selftest`, `homing`, `calibrate`, `paused`, `fault_power`. Split `jam_recovery` into per-segment faults (`fault_feeder`, `fault_selector`, `fault_recombine`, `fault_count`). Add brownout → NVS preservation.
7. **Test plan artifact lives at** `/Users/mackieg/.gstack/projects/shuffle/mackieg-main-nogit-test-plan-20260410-142438.md`. Three tiers: Tier 0 (pure Python shuffle quality sim), Tier 1 (subsystem bench rigs), Tier 2 (full system validation).
8. **Targets section still required.** User to fill: BOM ceiling, cycle time ceiling, deck envelope, primary user (home vs pro-am), shuffle-quality acceptance metric, jam rate target.

## Gating sequence before V1 CAD

1. ✅ Write the Python shuffle-quality simulator (Tier 0). — `sim/shuffle_quality.py`, 10k trials × 9 architectures.
2. ✅ Fill in Targets section. — pro-am primary, $500 BOM, 30 s cycle, new KEM + new Bee envelope. See Targets section above.
3. ✅ Feeder separator bakeoff protocol written. — `docs/tests/feeder-bakeoff.md`, 4 candidates (friction+retard, escapement, vacuum, kicker+weight) × new KEM + new Bee. Ready to build rig.
4. ✅ Lock architecture based on Tier 0 + bakeoff results.
5. ✅ Datum/tolerance budget. — `docs/plans/datum-tolerance-budget.md`. 5 interface stackups analyzed. Critical: bin→recombine pickup (variable stack height) and recombine→feeder reload (0.1mm margin, needs squaring step).
6. ✅ Subsystem CAD scaffolding. — All 5 modules parametric in Build123d: feeder (skeleton), selector (carriage + MGN12H + belt drive), bin bank (complete), recombine (pusher/elevator + accumulator), output tray (pocket + spring backstop). Chassis stub remains.
7. ✅ Main shuffler firmware. — `firmware/shuffler/`, 1,942 lines. 13-state machine, TMC2209 UART, per-pass count invariants, NVS brownout recovery, OLED display, service mode.
8. ✅ Bakeoff rig firmware. — `firmware/bakeoff-rig/`, interrupt-driven dual-sensor classifier + host capture script.

**All software deliverables complete. Next: physical build (bakeoff rig → feeder bakeoff → lock P4 → refine CAD → print + assemble).**

## Tier 0 Results — 2026-04-10

Simulator: `sim/shuffle_quality.py`. 10,000 Monte Carlo trials per architecture, seed=42, N=52.
Full output: `docs/tests/shuffle-quality-results.txt`.

**Rising-sequence mean (uniform target ≈ 26.48, 7-riffle benchmark ≈ 24.96):**

| Architecture | Rising seq. | Adjacency preserved | ≈ Riffle equiv. | Verdict |
|---|---|---|---|---|
| True uniform (ideal) | 26.48 ± 2.10 | 0.98 | 10.0 | baseline |
| Riffle × 7 (Bayer-Diaconis) | 24.96 ± 2.06 | 1.15 | 7.0 | benchmark |
| **Current plan: 2-pass 8-bin FIFO** | **26.08 ± 2.11** | **1.45** | **~9.2** | **PASS** |
| 2-pass 8-bin LIFO | 26.11 ± 2.08 | 1.43 | ~9.3 | PASS |
| 2-pass 16-bin FIFO | 26.37 ± 2.12 | 1.11 | ~10 | PASS |
| 1-pass 16-bin FIFO | 24.88 ± 2.09 | 3.35 | ~7.0 | FAIL (below target) |
| 1-pass 24-bin FIFO | 25.46 ± 2.11 | 2.41 | ~7.6 | FAIL (marginal) |
| 1-pass 32-bin FIFO | 25.68 ± 2.10 | 2.01 | ~7.9 | FAIL (marginal) |
| 3-pass 8-bin FIFO | 26.46 ± 2.10 | 1.03 | ~10 | PASS |
| Slot-rack 52 | 26.48 ± 2.11 | 0.98 | ~10 | PASS |

**Finding that invalidates the CEO review pessimism:** Both CEO voices computed 2-pass 8-bin as ~2-3 riffle equivalents by framing it as a radix sort. That framing is wrong. A radix sort requires deterministic bin assignment by card rank; this architecture uses *random* bin assignment per pass, so within-bin order depends on the random arrival sequence of other cards, not the card's own identity. Two independent random digit assignments mix 52! down to ≈ 8^(2·52) = 2^312 bits of entropy budget, far more than the 226 bits in 52!. Empirically, 2-pass 8-bin lands within 0.4 rising sequences of true uniform — indistinguishable at the 95% CI level.

**Architecture decision — P1 LOCKED: 2-pass 8-bin FIFO.**

- Meets and exceeds the 7-riffle target (9.2 equivalent).
- Matches true uniform on rising sequences, Kendall tau, and displacement.
- Only metric where it lags uniform: adjacency preservation (1.45 vs 0.98 — ~0.5 more preserved adjacent pairs per deck). Negligible for poker.
- 3-pass 8-bin offers marginal improvement (1.03 adjacency vs 1.45) but costs a full extra pass. Not worth it.
- Slot-rack 52 is theoretically ideal but requires 52 addressable positions. Mechanism count kills it.
- 1-pass configurations (16/24/32 bin) all fail or are marginal. Two passes is the minimum.

**Premise P1 (randomization architecture): LOCKED at 2-pass 8-bin FIFO.**
**Premise P2 (bin count): LOCKED at 8.**
**Premise P3 (pass count): LOCKED at 2.**
**Premise P4 (feeder separator): still pending bakeoff protocol.**

Next step: feeder bakeoff protocol → Targets section → begin CAD.

## Decision Audit Trail

| # | Phase | Decision | Classification | Principle | Rationale |
|---|---|---|---|---|---|
| 1 | 1 | Skip Phase 2 (Design review) | Mechanical | P3 pragmatic | No software UI surface. Physical ergonomics belong in Eng review. |
| 2 | 1 | Skip Phase 3.5 (DX review) | Mechanical | P3 pragmatic | No developer-user scope. End user is a dealer. |
| 3 | 1 | Run both Claude subagent + Codex voices for CEO | Mechanical | P6 bias toward action | Both available; both complete before consensus. |
| 4 | 1 | Surface 0/6 CEO consensus to premise gate | Mechanical | — | Both voices disagreed with plan on every dimension. Premise gate is the non-auto-decided gate. |
| 5 | 1 | User selected: Validate first, then lock arch | User decision | — | Unlocks P1-P4; defers CAD until Tier 0 sim + Targets + feeder bakeoff exist. |
| 6 | 3 | Defer table-integration scope entirely to V2 | Mechanical | P2 boil lakes but stay in radius | Dual-constraint trap confirmed by both voices. |
| 7 | 3 | Require SSD1306 OLED for V1 (upgrade from LED-only) | Taste | P1 completeness + P3 pragmatic | $3 part; diff between "tune until works" and "engineered" per Claude subagent. |
| 8 | 3 | Require bin-drop sensor coverage (new requirement) | Mechanical | P1 completeness | Critical gap flagged by both voices; selector misroutes otherwise silent. |
| 9 | 3 | Per-pass count invariants required, not just end-to-end | Mechanical | P1 completeness | Codex #15 + Claude F15 both flagged; no pushback. |
| 10 | 3 | `jam_recovery` must split into per-segment recovery states | Mechanical | P5 explicit over clever | Both voices flagged; implementation is concrete. |
| 11 | 3 | Brownout → NVS state preservation required | Mechanical | P1 completeness | Claude F22; Codex #14 aligned; implementation is a 10-line handler. |
| 12 | 3 | Generate test plan artifact at disk | Mechanical | P1 completeness | Required output per skill. |

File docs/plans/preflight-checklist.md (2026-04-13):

# First Power-On Preflight Checklist

Date: 2026-04-12

Go through this before applying 12V power to anything. Mistakes here fry TMC2209 drivers ($5 each, fragile).

---

## Phase 0: Before Any Power

- [ ] **Inspect all solder joints** under magnification. Cold joints on TMC2209 UART pins are the #1 failure mode.
- [ ] **Verify 12V PSU polarity.** Measure with multimeter before connecting. Some cheap PSUs have swapped terminal labels.
- [ ] **Verify 5V buck converter output.** Connect 12V in, measure output with multimeter. Adjust trim pot to 5.0V ± 0.1V. Do this BEFORE connecting the ESP32.
- [ ] **Check TMC2209 MS1/MS2 addresses.** Reference `motor-setup-lumen.md`. Each driver must have a unique address.
- [ ] **Motor coil check.** For each motor, confirm coil pairs with the touch-and-spin method. Swapped coils = motor vibrates in place instead of rotating.
- [ ] **No shorts.** Continuity-check VM to GND on each TMC2209 board. Should read open circuit (megaohms). If shorted, find the solder bridge before proceeding.

## Phase 1: ESP32 Only (USB Power)

- [ ] Connect ESP32 via USB (no 12V yet)
- [ ] Flash shuffler firmware: `cd firmware/shuffler && pio run -t upload`
- [ ] Open serial monitor at 115200 baud
- [ ] Verify boot message appears: "ShuffleDeck V1 — Boot Self-Test"
- [ ] OLED should display boot screen (if connected via I2C)
- [ ] Type `status` in serial monitor — should report all motors as COMM_FAIL (expected, they have no power yet)

## Phase 2: Single Motor Test (12V)

Test ONE motor at a time. If a driver is wired wrong, you only lose one.

- [ ] Connect 12V PSU to ONE TMC2209 only (the feeder, addr 0)
- [ ] Connect 5V buck output to ESP32 VIN (or continue using USB power)
- [ ] Connect UART bus (GPIO 12/13) to the feeder TMC2209 only
- [ ] Type `status` — feeder should report COMM_OK
- [ ] Type `service` to enter service mode, then `jog feed+` — motor should rotate ~1 rev
- [ ] **Check motor temperature** after jogging. Should be barely warm. If hot, current setting is too high or coils are swapped.
- [ ] **Listen.** StealthChop should be nearly silent. If the motor screams, UART communication may have failed and the driver fell back to defaults.

Repeat for each motor (enter `service` mode first, `exit` to leave):

- [ ] Selector X (addr 1): `jog sel+`
- [ ] Recombine X (addr 2): `jog recx+`
- [ ] Recombine Z (addr 3): `jog recz+`

## Phase 3: All Motors Together

- [ ] Connect all 4 TMC2209 boards to 12V and UART bus
- [ ] Type `status` — all 4 should report COMM_OK
- [ ] Type `selftest` — each axis jogs forward 50 steps and back
- [ ] **Watch for missed steps.** If a motor doesn't return to its start position, check mechanical binding or increase current by 100mA.

## Phase 4: Sensor Check

- [ ] Connect each TCRT5000 module one at a time
- [ ] Type `sensors` — should show 6 sensor states (HIGH = clear, LOW = blocked)
- [ ] Wave a card in front of each sensor — state should flip
- [ ] Verify ISR triggers: type `events` after triggering each sensor. Event queue should show the trigger with timestamp.

Sensor positions and expected GPIO:

| Sensor | GPIO | Location |
|---|---|---|
| Feed exit | 34 | After feeder roller |
| Post-singulation | 35 | Confirms single card |
| Selector throat | 36 | Card entering selector |
| Bin entry | 39 | Card landed in bin |
| Recombine pickup | 23 | Card grabbed by elevator |
| Output | 22 | Card in output tray |

## Phase 5: Full Integration

- [ ] Type `shuffle` in serial monitor, or press the Shuffle button (GPIO 15)
- [ ] State machine should advance: IDLE → FEED_PASS1 → ...
- [ ] Without cards, it will hit MISS_TIMEOUT after ~1 second (no card detected at feed exit sensor). This is expected.
- [ ] Verify the OLED shows state transitions
- [ ] Press Stop button (GPIO 0) — should halt all motors and enter JAM_RECOVERY

## Phase 6: First Card Test

- [ ] Load 5-10 cards (not the full deck) into the feeder hopper
- [ ] Press Shuffle
- [ ] Watch for: card singulation, selector routing, bin entry confirmation
- [ ] If a card jams: note which sensor timed out, check card path alignment at that point
- [ ] Gradually increase to full 52-card deck

---

## Troubleshooting Quick Reference

| Symptom | Likely Cause | Fix |
|---|---|---|
| Motor doesn't move | EN pin stuck HIGH | Check enable pin wiring, verify `motor_enable()` pulls LOW |
| Motor vibrates but doesn't rotate | Coil wires swapped | Swap one coil pair (e.g., swap A+ and A-) |
| Motor screams (loud whine) | UART failed, no StealthChop | Check UART wiring, verify 1kΩ resistor on TX line |
| TMC2209 version reads 0x00 | No UART communication | Check TX/RX wiring, verify VIO connected to 3.3V |
| TMC2209 version reads 0xFF | Bus contention | Check for shorted UART lines, verify MS1/MS2 addresses are unique |
| Sensor always reads LOW | Sensor too close to surface | Adjust mount distance to 3-5mm, check for ambient IR interference |
| Sensor never triggers | Sensor dead or wired wrong | Check VCC/GND, verify correct GPIO pin (34-39 are input-only on ESP32) |
| OLED blank | Wrong I2C address | Try 0x3D instead of 0x3C, run I2C scanner sketch |
| ESP32 reboots on motor start | Power spike | Add 100µF electrolytic cap across 5V rail, use separate 5V supply |
| Cards double-feed | Retard pad worn or wrong pressure | Increase spring preload, replace pad material, check roller O-ring condition |
| Cards skew in selector | Guide channel too tight/loose | Sand or shim the card guide on the selector carriage |

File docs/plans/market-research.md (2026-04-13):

# Market Research — Smart Poker Table Kit

Date: 2026-04-12

## The gap

No integrated consumer "smart poker table" kit exists. The market is fragmented:

| Segment | Product | Price | RFID? | Table-install? |
|---|---|---|---|---|
| Cheap consumer | Amazon shufflers (Srkmxzr, COYEUX) | $25-60 | No | No |
| Pro consumer | Shuffle Tech ST1000 | $650-800 | No | Yes ($140 adapter) |
| Custom build | No Tilt, BBO custom tables | $3,000-5,000+ | Optional | Yes |
| Casino/enterprise | PokerTek, Shuffle Master | $5,000-50,000+ | Yes | Yes |
| Software only | PokerGFX, Smart Poker Table | $500-2,000+ | Requires DIY HW | N/A |

**The gap: $1,500-2,500 for an integrated shuffler + RFID kit.** Nobody is selling this.

## RFID poker cards exist

- **Faded Spade** — official cards of WPT, Moneymaker Tour, Live at the Bike. ~$10-15/deck retail.
- **Standard: 13.56MHz HF** (ISO14443/ISO15693). Compatible with cheap NFC readers ($4 Arduino modules).
- Poker-grade RFID cards available from Faded Spade, RFIDup, NFC Tag Factory, TP-RFID.
- Read range ~1.5m — adequate for under-felt antenna array.

## Target buyers

1. **Serious home game hosts** — $200+ buy-in weekly games. ~10,000-50,000 in North America. Already spending $2,000-$5,000 on tables + accessories.
2. **Poker content creators / streamers** — ~500-2,000 actively monetizing. Currently piecing together RFID + streaming solutions manually. Exploding market post-COVID.
3. **Small card room operators** — ~2,000-5,000 venues. Using PokerTek or custom setups.
4. **Tournament organizers** — want broadcast-quality hole card display.

## Competitive landscape

### Direct competitors (none integrated)

- **Shuffle Tech ST1000** ($650-800) — quality shuffler, no RFID, table-mountable. Closest to our shuffler module.
- **PokerGFX** — RFID streaming software with optional hardware bundles. Tiered licensing (hobbyist to enterprise). Requires DIY hardware assembly.
- **Smart Poker Table (rfidpokertable.com)** — all-in-one software for RFID tables. 
- **RF Poker** — state-of-the-art RFID equipment for streaming. Enterprise pricing.

### DIY ecosystem

- Arduino + RC522 RFID reader modules (~$4 each) can read NFC poker cards.
- Multiple hobbyist builds documented (Arduino Forum, Poker Chip Forum, HN).
- One developer built a working RFID table for **<$300** (bare-bones prototype).
- Community interest is high but no polished product exists.

## Why this hasn't been done

1. **No VC interest** — "poker peripherals" triggers gaming/regulatory concerns.
2. **Small market** — home poker table market is ~$500M/year in North America (niche).
3. **Engineering complexity** — RFID + shuffler + streaming software integration is hard.
4. **Enterprise focus** — all pro RFID vendors target casinos (high margins).
5. **No cannibalization incentive** — BBO, Just Poker Tables have no reason to offer a $2,500 kit when they sell $5,000 custom tables.

## Our positioning

| | ShuffleDeck Core | Shuffle Tech ST1000 | Amazon shufflers |
|---|---|---|---|
| Price | ~$500 (kit) | $650-800 | $25-60 |
| Shuffle quality | 9.2 riffles (proven) | Unknown (proprietary) | Terrible |
| Table-installable | Yes | Yes ($140 adapter) | No |
| RFID capable | Yes (add-on) | No | No |
| Open source | Yes | No | No |
| Jam rate | TBD (target <1/500) | Low | High |

**RFID add-on (~$300):** 13.56MHz antenna array under felt + ESP32 reader + streaming overlay software. Nothing like this exists at consumer price points.

## Recommended product line

1. **ShuffleDeck Core** (~$500) — the shuffler we're building. DIY kit or pre-assembled.
2. **ShuffleDeck RFID** (~$300) — add-on antenna array + reader. Works with Faded Spade cards.
3. **ShuffleDeck Stream** (free, open-source) — OBS overlay plugin for streaming with RFID or manual input.

Total kit: ~$800 + $10-15 for RFID cards. Vs. $5,000+ for anything comparable.

## Risks

- **Market size ceiling** — realistic addressable market is 5,000-20,000 buyers globally.
- **Price compression** — if successful, BBO/Just Poker will copy.
- **Regulatory** — some jurisdictions may restrict "automated dealing" equipment. Need legal review.
- **Customer acquisition** — no established channel for "smart poker table" category. Need influencer/YouTube strategy.

## Next steps

1. Landing page with waitlist (capturing demand signal).
2. Customer interviews — 10-15 serious home game hosts.
3. Regulatory review — gaming attorneys in CA, NV, TX, NY.
4. RFID reader prototype — ESP32 + RC522 + Faded Spade deck, prove read-through-felt works.
5. Pricing validation — would you pay $500/$800/$1,500?

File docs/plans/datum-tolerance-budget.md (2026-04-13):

# Datum and Tolerance Budget — Single-Deck Card Shuffler

Date: 2026-04-12
Status: Draft

## Overview

This document defines the datum scheme, interface tolerance stackups, and critical dimensions for the single-deck automatic card shuffler. The goal is to identify where tolerance accumulation eats into functional clearance so that adjustability is designed into the right places before CAD freeze.

All dimensions reference `cad/constants.py`. Card nominal: 63.5 x 88.9 x 0.3 mm (poker). Print material: PETG. Default print tolerance: +/-0.2 mm. Tight print tolerance: +/-0.1 mm.

---

## 1. Datum Scheme

Three orthogonal datums define the machine coordinate system. Every module registers to this chain.

### Primary Datums

| Datum | Feature | Description |
|---|---|---|
| **A** (Z reference) | Chassis base plate, top surface | Flat plane the entire machine sits on. All vertical dimensions reference upward from here. Printed flat on the build plate — best surface accuracy. |
| **B** (Y reference) | Left side rail, inner face | A continuous wall or rail running the full card-travel direction. The "operator side" datum. All lateral (card-width) dimensions reference inward from here. |
| **C** (X reference) | Feeder-end stop, inner face | A single transverse wall at the feeder end of the chassis. All longitudinal (card-travel) dimensions reference forward from here. |

### Module Registration

Each module bolts to the chassis and locates against the datum chain:

| Module | Registers to | Location method |
|---|---|---|
| Feeder | A + B + C | Bolt-down to base plate (A). Side rail contact (B). End stop contact (C). |
| Selector | A + B | Bolt-down to base plate (A). Side rail contact (B). Longitudinal position set by feeder exit — slotted holes allow +/-2 mm X adjustment. |
| Bin bank | A + B | Bolt-down to base plate (A). Side rail contact (B). X position set by selector gate range — slotted holes allow +/-2 mm X adjustment. |
| Recombine | A + B | Bolt-down to base plate (A). Side rail contact (B). X position adjustable. |
| Output tray | A + B | Bolt-down to base plate (A). Side rail contact (B). X position adjustable. |

**Key principle:** Datum B (side rail) is the card-width alignment reference for the entire machine. Every card guide, bin wall, and funnel references its "left" edge off B. This means lateral tolerance stacks are always one-sided — they accumulate from B toward the right, never from both sides toward center.

---

## 2. Interface Tolerance Stackups

For each critical interface, the tolerance chain is calculated worst-case (all contributors add). The available clearance is the designed gap that must absorb the total stack.

### Constants used in calculations

| Symbol | Value | Source |
|---|---|---|
| Card width | 63.5 mm | constants.py |
| Card height | 88.9 mm | constants.py |
| Card thickness | 0.3 mm | constants.py |
| Bin internal width | 65.5 mm (1.0 mm clearance per side) | constants.py |
| Bin internal depth | 90.9 mm (1.0 mm clearance per side) | constants.py |
| Bin entry funnel chamfer | 3.0 mm at 45 deg | constants.py |
| Print tol default | +/-0.2 mm | constants.py |
| Print tol tight | +/-0.1 mm | constants.py |
| Card warp (new deck, V1 envelope) | up to 0.5 mm bow across width | Empirical, new KEM/Bee |
| PETG thermal expansion | ~60 um/m/degC, negligible at room temp deltas of +/-10C over 500 mm span = +/-0.3 mm | Material property |

---

### Interface 1: Feeder Exit Throat --> Selector Entry

**What happens here:** A single card exits the friction roller / retard pad nip and enters a guided path toward the selector gate. The card is moving at ~120 mm/s. Misalignment causes skew, nose-dive, or jam.

**Critical axis:** Card width (lateral, Y). Card must be centered in the guide channel.

| # | Contributor | Nominal | Tolerance | Notes |
|---|---|---|---|---|
| 1 | Feeder exit guide width (printed) | 65.5 mm | +/-0.2 mm | Two walls, each +/-0.2 mm, but both ref from Datum B so only right wall floats |
| 2 | Selector entry guide width (printed) | 65.5 mm | +/-0.2 mm | Same datum chain |
| 3 | Feeder-to-selector lateral alignment (assembly) | 0 mm offset | +/-0.3 mm | Two separate printed parts bolted to chassis; each locates off Datum B with bolt clearance |
| 4 | Card width variation | 63.5 mm | +/-0.25 mm | Manufacturing tolerance on poker cards |
| 5 | Card warp (bow across width) | 0 mm | up to 0.5 mm | Effective width increase from bow |

**Nominal clearance:** Guide width - card width = 65.5 - 63.5 = 2.0 mm total (1.0 mm per side).

**Worst-case stack (card too wide for gap):**
- Guide narrows by: 0.2 (feeder wall) + 0.2 (selector wall) + 0.3 (misalignment) = 0.7 mm
- Card widens by: 0.25 (card tolerance) + 0.5 (warp) = 0.75 mm
- Total stack consuming clearance: 0.7 + 0.75 = **1.45 mm**

**Available clearance: 2.0 mm. Margin: 0.55 mm.** PASS — but only 0.55 mm margin at worst case.

**Vertical (Z) concern:** The card must transfer from the feeder's lower guide surface to the selector's lower guide surface without a step. Both surfaces reference Datum A (base plate).

| # | Contributor | Tolerance |
|---|---|---|
| 1 | Feeder guide surface height (from A) | +/-0.2 mm |
| 2 | Selector guide surface height (from A) | +/-0.2 mm |
| 3 | Assembly seating on base plate | +/-0.1 mm |

**Worst-case step: 0.5 mm.** A 0.5 mm downward step will catch card leading edges. A 0.5 mm upward step forces a ramp. Either causes jams at 120 mm/s.

**FLAG: This interface needs a lead-in chamfer or ramp at the selector entry (minimum 1 mm tall, 3 mm long, 18-deg slope) to handle the worst-case step. Alternatively, make the feeder and selector a single printed part to eliminate contributors 1-3.**

---

### Interface 2: Selector --> Bin Entry Funnels

**What happens here:** The selector gate positions over one of 8 bins, and the card drops by gravity into the bin. The card must clear the funnel opening despite selector positional error.

**Critical axis:** Lateral (Y) position of card drop relative to bin center.

| # | Contributor | Nominal | Tolerance | Notes |
|---|---|---|---|---|
| 1 | Selector gate position (stepper repeatability) | Bin center | +/-0.1 mm | NEMA17 + microstepping, conservative |
| 2 | Selector rail/bearing play | 0 | +/-0.15 mm | Linear rail or printed slide |
| 3 | Bin bank lateral position (assembly to Datum B) | Per design | +/-0.3 mm | Bolted to chassis |
| 4 | Bin wall print tolerance | Per design | +/-0.2 mm | Each bin wall position |
| 5 | Card lateral drift during drop | 0 | +/-1.0 mm | Gravity drop with air resistance, card curl; ~20-40 mm drop height |
| 6 | Card warp (width effective increase) | 0 | +0.5 mm | Bow makes card wider |

**Available clearance:** Bin internal width = 65.5 mm. Card width = 63.5 mm. Per-side clearance = 1.0 mm. Funnel chamfer adds 3.0 mm effective catch zone at top (so entry opening is ~71.5 mm at the top lip).

**Worst-case offset from center of bin:**
0.1 + 0.15 + 0.3 + 0.2 + 1.0 = **1.75 mm lateral offset**

Plus card effective half-width increase from warp: 0.25 mm per side.

**Total: card edge can be 2.0 mm off from nominal position.**

Against funnel entry half-width of (71.5 - 63.5) / 2 = **4.0 mm.** PASS with 2.0 mm margin at the funnel lip.

Against bin internal half-clearance of 1.0 mm once past the funnel: the card must settle before contacting the straight walls. The 3.0 mm chamfer at 45 degrees provides a centering ramp.

**FLAG: Card lateral drift during drop (contributor 5) dominates this stack. If drop height exceeds ~40 mm, increase funnel chamfer from 3.0 mm to 5.0 mm. Consider adding guide fingers or a short chute below the selector gate to reduce free-fall distance.**

**Depth (X) axis:** Bin internal depth = 90.9 mm vs card height 88.9 mm = 1.0 mm per side. Same funnel chamfer applies. Similar analysis: PASS with the funnel, but the depth clearance is tight once the card is inside the bin.

---

### Interface 3: Bin Bank --> Recombine Pickup

**What happens here:** The recombine module must grab a partial stack of 1-10 cards from a bin and transfer it to a temporary assembly area. The stack could be as thin as 0.3 mm (1 card) or as thick as 3.0 mm (10 cards). Cards may be slightly misaligned within the bin.

**Critical dimensions:**

| # | Contributor | Value/Tolerance | Notes |
|---|---|---|---|
| 1 | Stack height variation | 0.3 - 3.0 mm | 1-10 cards at 0.3 mm each |
| 2 | Card misalignment within bin | +/-1.0 mm lateral | Cards settle imperfectly against bin walls |
| 3 | Bin floor height (from Datum A) | Nominal +/-0.3 mm | Print tolerance + assembly |
| 4 | Recombine pickup Z position (from Datum A) | Nominal +/-0.3 mm | Print tolerance + assembly |
| 5 | Recombine pickup lateral alignment to bin | Nominal +/-0.5 mm | Two separate assemblies, each referenced to B |

**The core problem:** The pickup mechanism must:
- Enter the bin without colliding with bin walls (needs ~0.5 mm clearance on each side)
- Contact the top card of a stack whose height varies by 10:1
- Grip the partial stack without disturbing the stack below (no telescoping)
- Extract vertically or laterally without snagging

**Worst-case Z mismatch:** Bin floor and pickup reference both have +/-0.3 mm from Datum A. Combined: +/-0.6 mm. For a 1-card stack (0.3 mm thick), the pickup could miss entirely.

**FLAG: This is the highest-risk interface in the machine. A fixed-height pickup cannot work. Requirements:**
1. **Compliant or sensor-guided Z approach** — the pickup must find the top of the stack, not go to a fixed Z coordinate. Spring-loaded fingers, a contact switch, or a beam sensor to detect stack-top height.
2. **Lateral clearance is very tight.** Bin internal width = 65.5 mm. Pickup mechanism + its travel clearance must fit in ~63.5 mm or less to avoid bin wall contact. This leaves essentially zero margin for mechanisms wider than the card.
3. **Consider bottom extraction** (pushing stack up from below through a slot in the bin floor) instead of top pickup. This eliminates the stack-height-finding problem entirely — you always push from a known datum (the floor).

---

### Interface 4: Recombine --> Feeder Input (Pass 2 Reload)

**What happens here:** After pass 1, the recombined 52-card stack is transferred back into the feeder hopper for pass 2. The stack must enter the hopper, settle against the backstop, and be singulatable without manual intervention.

| # | Contributor | Value/Tolerance | Notes |
|---|---|---|---|
| 1 | Recombine output stack squareness | +/-1.5 mm skew across stack | Accumulated from multiple bin pickups |
| 2 | Recombine output height above hopper | Variable | Transport path dependent |
| 3 | Hopper side rail width | 65.5 mm +/-0.2 mm | Printed, references Datum B |
| 4 | Stack effective width (52 cards, some skew) | 63.5 mm + 1.5 mm skew = 65.0 mm | Worst case |
| 5 | Hopper backstop position | Nominal +/-0.3 mm | Print + assembly |

**Nominal clearance:** Hopper width (65.5 mm) - card width (63.5 mm) = 2.0 mm.

**Worst-case stack width with skew:** 65.0 mm in a 65.1 mm hopper (worst-case narrow). **Margin: 0.1 mm.** FAIL at worst case — skewed stack will wedge in the hopper.

**FLAG: This interface requires a squaring step before reload.** Options:
1. **Vibration jogger** — momentary vibration motor to settle the stack square before inserting into hopper. Simple, no moving parts besides the motor.
2. **Side-tap plate** — a spring-loaded plate that taps the long edge of the stack to register it against a datum wall before transfer.
3. **Wider hopper with active alignment** — increase hopper clearance to 3.0 mm per side (69.5 mm internal) and add a closing guide that narrows during feed.

The recombine-to-hopper transfer is also the only interface where the full 52-card stack moves as a unit. Stack height at this point: ~15.6 mm nominal, up to 17.0 mm with air gaps. The transport mechanism must handle a 17 mm tall, potentially skewed stack without dropping or collapsing it.

---

### Interface 5: Recombine --> Output Tray (Final Delivery)

**What happens here:** After pass 2, the final recombined deck is delivered to the output tray. Same stack-squareness concern as Interface 4, but the output tray can be more forgiving because the stack does not need to be singulatable — it just needs to be presentable.

| # | Contributor | Value/Tolerance | Notes |
|---|---|---|---|
| 1 | Stack squareness after pass 2 recombine | +/-1.5 mm | Same as Interface 4 |
| 2 | Output tray width | Designed for generous clearance | Target 69-70 mm internal |
| 3 | Output tray depth | Designed for generous clearance | Target 93-95 mm internal |
| 4 | Drop height into tray | Minimize | Free-fall skews the stack |

**Recommendation:** Size the output tray at 70 x 94 mm internal (3.25 mm clearance per side on width, 2.55 mm per side on depth). This is generous enough that worst-case skew and print tolerance will not cause the stack to wedge. Add slight taper to all four walls (2-3 deg draft) so the stack self-centers as it settles.

**This interface is LOW RISK provided the tray is sized generously.** The squaring step before Interface 4 (pass 2 reload) is the one that matters.

---

## 3. Critical Dimensions Table

Every dimension that matters at a module interface, its nominal value, tolerance, and datum reference.

### Feeder Module

| Dimension | Nominal (mm) | Tolerance (mm) | Datum | Notes |
|---|---|---|---|---|
| Exit throat width | 65.5 | +/-0.2 | B | Card width + 2 x 1.0 clearance |
| Exit throat height (gap) | 0.35 | +/-0.05 | A | Single card must pass, double must not |
| Roller center height above base | TBD | +/-0.1 | A | Tight — drives nip geometry |
| Retard pad contact line height | TBD | +/-0.1 | A | Must match roller center +/- 0.1 |
| Hopper side rail spacing | 65.5 | +/-0.2 | B | Same as throat |
| Hopper floor inclination angle | ~30 deg | +/-2 deg | A | Gravity feed angle |
| Backstop position from throat | ~95 | +/-0.5 | C | Card height + clearance |

### Selector Module

| Dimension | Nominal (mm) | Tolerance (mm) | Datum | Notes |
|---|---|---|---|---|
| Entry guide width | 65.5 | +/-0.2 | B | Must match feeder exit |
| Gate travel range | Spans 8 bins | +/-0.1 per position | B | Stepper positioning |
| Gate-to-bin-top gap (Z) | 2-5 | +/-0.5 | A | Drop height, minimize |
| Entry guide height above base | Same as feeder exit | +/-0.2 | A | Step must be < 0.5 mm |

### Bin Bank

| Dimension | Nominal (mm) | Tolerance (mm) | Datum | Notes |
|---|---|---|---|---|
| Bin internal width | 65.5 | +/-0.2 | B | Per constants.py |
| Bin internal depth | 90.9 | +/-0.2 | B, C | Per constants.py |
| Bin internal height | 20.0 | +/-0.3 | A | Room for 10 cards + extraction |
| Bin wall thickness | 2.0 | +/-0.2 | -- | Structural |
| Bin spacing (gap between bins) | 2.0 | +/-0.2 | B | Selector access |
| Bin entry funnel chamfer | 3.0 | +/-0.3 | -- | 45-deg lead-in |
| Bin floor height above base | TBD | +/-0.2 | A | Critical for recombine pickup |
| Bin pitch (center-to-center) | 69.5 | +/-0.3 | B | 65.5 + 2x2.0 wall + 2.0 spacing... see note |

**Note on bin pitch:** Bin pitch = bin internal width (65.5) + wall (2.0) + spacing (2.0) + wall (2.0) = 71.5? No — adjacent bins share a wall. Pitch = internal width (65.5) + one wall thickness (2.0) + spacing (2.0) = 69.5 mm. Over 8 bins the total bank width = 8 x 65.5 + 9 x 2.0 (walls) + 7 x 2.0 (spacings) = 524 + 18 + 14 = 556 mm. This is large. Tolerance accumulation over 556 mm at 0.2 mm per feature could reach several mm at the far end.

**FLAG: Bin bank should be printed as one piece (or two halves that register to each other via alignment pins) to avoid inter-bin tolerance accumulation from separate assembly. If printing as one piece exceeds bed size (~250 mm typical), split into two 4-bin halves with a kinematic pin joint.**

Actually, recalculating: if each bin shares walls with its neighbor, then pitch = internal width + shared wall + gap = 65.5 + 2.0 + 2.0 = 69.5 mm. Total bank width = 8 x 69.5 - 2.0 (last gap not needed) + 2.0 (outer wall at each end) = 556 + 2 = 558 mm. This does not fit on any common print bed as one piece. **Two 4-bin halves at ~280 mm each, or four 2-bin quarters at ~141 mm each.**

### Recombine Module

| Dimension | Nominal (mm) | Tolerance (mm) | Datum | Notes |
|---|---|---|---|---|
| Pickup mechanism width | < 63.5 | +/-0.2 | B | Must fit inside bin |
| Pickup Z travel | 0 to 20.0 | +/-0.1 | A | Must reach bin floor |
| Pickup lateral alignment to bin | 0 offset | +/-0.5 | B | Combined assembly tolerance |
| Stack assembly area width | 67.0 | +/-0.3 | B | Wider than card to allow stack building |

### Output Tray

| Dimension | Nominal (mm) | Tolerance (mm) | Datum | Notes |
|---|---|---|---|---|
| Tray internal width | 70.0 | +/-0.3 | B | Generous |
| Tray internal depth | 94.0 | +/-0.3 | B, C | Generous |
| Tray internal height | 25.0 | +/-0.5 | A | Full deck + margin |
| Wall draft angle | 2-3 deg | +/-1 deg | -- | Self-centering |

---

## 4. Print-Specific Considerations

### PETG Shrinkage

PETG shrinks approximately 0.4-0.6% during cooling. On a 65.5 mm bin width, that is 0.26-0.39 mm. Most slicers compensate for this, but compensation is never perfect.

**Recommendation:** Design to nominal dimensions and tune with test prints. For critical fits (bearing bores, shaft holes), print a test coupon first and measure actual shrinkage on your printer/filament combination. Apply a per-printer correction factor in `constants.py` rather than baking a shrinkage guess into CAD dimensions.

### Layer Height Effects

Vertical dimensions are quantized to the layer height (0.2 mm per constants.py). Any vertical dimension that is not a multiple of 0.2 mm will be rounded by the slicer.

**Affected critical dimensions:**
- Feeder throat gap (0.35 mm nominal) — will print as either 0.2 mm (too tight) or 0.4 mm (acceptable). **Design to 0.4 mm and tune with shims or retard pad adjustment.**
- Bin floor thickness (1.5 mm) — not a problem, 1.5 / 0.2 = 7.5 layers, slicer rounds to 8 = 1.6 mm. Acceptable.
- Bin entry funnel chamfer — printed as staircase steps. The 45-deg chamfer will have 0.2 mm steps. At 3.0 mm chamfer height, that is 15 steps. Adequate for card sliding but consider sanding or printing at 0.12 mm layer height for the funnel region.

### First-Layer Elephant Foot

The first layer is typically over-extruded by 0.1-0.2 mm (elephant foot). This affects:
- **Bin internal dimensions at the floor:** The first few layers of bin walls will be 0.1-0.2 mm thicker, reducing internal width by 0.2-0.4 mm at the bottom. For a bin, this is a self-clearing problem since cards stack from the bottom and push past it. But for the feeder throat where the bottom surface IS the critical surface, elephant foot must be addressed.
- **Module base surfaces that sit on the chassis plate:** Elephant foot on the contact surface creates a slight convexity. Not a problem for bolt-down registration since the bolt clamp force flattens it.

**Mitigation:** Enable elephant foot compensation in slicer (typically -0.1 to -0.2 mm first layer horizontal expansion). For the feeder throat specifically, print throat-side-down so the critical gap dimension is defined by the top surface of the print, not the first layer.

### Bearing Bore Tolerances

608 bearings (8 mm ID, 22 mm OD, 7 mm wide) are called out in the design. Printed bores for press-fit bearings:

- **Bore diameter:** Print at 22.0 + 0.1 mm = 22.1 mm (tight fit per PRINT_TOL_TIGHT). Test fit; ream with a drill bit if too tight.
- **Bore roundness:** Printed bores are not truly round — they are polygonal approximations. A bore at 0.2 mm layer height with standard faceting will have ~0.05-0.1 mm out-of-round. Acceptable for 608 bearing press-in.
- **Bore depth:** 7.0 mm bearing in a printed pocket. Print pocket at 7.2 mm to allow full seating. The slicer will round 7.2 / 0.2 = 36 layers exactly.

### Heat-Set Insert Bores

Per constants.py: M3 heat-set bore = 3.2 mm, M4 = 4.8 mm. These dimensions already include the slight undersizing needed for the brass insert to melt into the plastic. No additional tolerance adjustment needed, but:
- Print insert bores vertically (bore axis = Z axis) for best roundness.
- If a heat-set insert is in a horizontal bore (bore axis = X or Y), increase bore diameter by 0.1 mm to compensate for layer staircase ovality.

---

## 5. Recommendations

### Where to Use Kinematic Mounts vs Simple Bolt-Down

| Interface | Mounting Method | Rationale |
|---|---|---|
| Feeder to chassis | **Kinematic: 3-point with adjustment** | Highest-risk singulation module. Needs nip height tuning, lateral alignment, and angle adjustment. Use two pins in slotted holes (constrains Y and rotation) plus one bolt (constrains X). Shims under pin seats for Z adjustment. |
| Selector to chassis | **Bolt-down with slotted holes** | Needs X adjustment (longitudinal) to set gap to feeder exit. Y alignment inherits from Datum B rail contact. 2-4 bolts in X-slotted holes. |
| Bin bank to chassis | **Bolt-down, tight, no adjustment** | Once printed correctly, bin positions are internal and self-consistent. Register to Datum B rail. The selector adjusts to the bins, not the other way around. |
| Recombine to chassis | **Kinematic: linear rail or adjustable slide** | Must align precisely to each bin in sequence. Either the recombine module travels on a rail (inherently self-aligning to the bin bank) or it has XY adjustment at its mount point. |
| Output tray to chassis | **Simple bolt-down, loose tolerance** | Generous internal dimensions make precision unnecessary. Two bolts, done. |

### Where Adjustability is Required

1. **Feeder nip gap** — MUST be adjustable. The gap between the friction roller and the retard pad determines singulation reliability. Use an eccentric cam or a screw-and-locknut arrangement to set the gap, then lock it. Target: 0.30-0.40 mm, adjustable in ~0.05 mm increments.

2. **Feeder-to-selector Z step** — Either eliminate by making them one part, or provide a shim stack (0.1, 0.2, 0.3 mm shims) under the selector to match heights.

3. **Selector home/zero position** — Software-adjustable (homing sensor + offset in firmware). Physical endstop must be repeatable to +/-0.1 mm. Use a microswitch with a precision flag, not a printed bump.

4. **Recombine pickup Z zero** — Must be calibrated per-build. Either a contact sensor on the pickup mechanism, or a firmware-stored offset calibrated during assembly.

### Where Tight Tolerance is Justified

- **Feeder throat gap:** +/-0.05 mm. This is the singulation gate. Worth printing test coupons and selecting.
- **Roller and retard pad contact geometry:** +/-0.1 mm. Drives nip force consistency.
- **Selector stepper position repeatability:** +/-0.1 mm. Determines correct bin selection.
- **Bearing bores:** +/-0.1 mm. Standard for press-fit.

### Where Loose Tolerance is Fine

- **Bin internal dimensions:** +/-0.3 mm. The 1.0 mm per-side clearance is ample.
- **Output tray dimensions:** +/-0.5 mm. Oversized by design.
- **Electronics bay dimensions:** +/-1.0 mm. Nothing critical.
- **Chassis overall dimensions:** +/-1.0 mm. Cosmetic only.
- **Fastener clearance holes:** Already oversized per constants.py (M3 clearance = 3.4 mm for 3.0 mm bolt).

### Summary of Flagged Interfaces

| Interface | Risk | Action Required |
|---|---|---|
| Feeder exit --> selector entry (Z step) | **HIGH** | Add lead-in chamfer/ramp at selector entry, or combine into one printed part |
| Selector --> bin entry (lateral drift) | **MEDIUM** | Increase funnel chamfer to 5 mm if drop height > 40 mm; add guide chute |
| Bin bank --> recombine pickup | **CRITICAL** | Fixed-height pickup will not work. Needs compliant/sensor-guided Z, or switch to bottom-push extraction |
| Recombine --> feeder pass 2 reload | **HIGH** | Stack squareness eats all clearance. Requires squaring step (jogger or tap plate) before reload |
| Recombine --> output tray | **LOW** | Size tray generously, add wall draft. No special measures needed |

### Bin Bank Printing Strategy

The full 8-bin bank at ~558 mm wide will not fit on a single print bed. Options:

1. **Two 4-bin halves (~280 mm each):** Fits large-format printers (Bambu X1 at 256 mm is close; Prusa XL at 360 mm fits). Join with alignment dowel pins (2x M4 pins) and bolts. Tolerance at the joint: +/-0.3 mm, absorbed by the 2.0 mm inter-bin spacing.

2. **Four 2-bin quarters (~141 mm each):** Fits any printer. More joints = more accumulated tolerance. Each joint adds +/-0.3 mm. Over 3 joints: +/-0.9 mm worst case from first bin to last. The selector must be calibrated to actual bin positions, not nominal.

3. **Individual bins bolted to a common rail:** Maximum flexibility but worst tolerance accumulation. Only use if bin count may change (e.g., testing 6 vs 8 vs 10 bins during development).

**Recommendation for V1:** Option 2 (four 2-bin quarters) for printer compatibility, with the selector homed and calibrated to measured bin positions stored in firmware. This decouples print accuracy from bin-selection accuracy.

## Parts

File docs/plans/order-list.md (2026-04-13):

# Order List — What to Buy

Date: 2026-04-12

**Already have:** 4× NEMA17 (Lumen 3D printer), 1× ESP32 DevKit, 4× TMC2209 drivers

Everything below is what you still need. Organized by order (Amazon first for speed, AliExpress for the linear rails).

---

## Amazon Order 1 — Electronics + Misc (~$50)

| Item | Search Term | Qty | ~Price |
|---|---|---|---|
| OLED display | "SSD1306 0.96 inch OLED I2C 128x64" | 1 | $4 |
| IR sensors | "TCRT5000 IR reflective sensor module" (10-pack) | 1 pack | $4 |
| Power supply | "12V 10A power supply enclosed" (Mean Well or clone) | 1 | $14 |
| Buck converter | "MP1584EN 5V buck converter module" (3-pack) | 1 pack | $3 |
| IEC inlet | "IEC C14 panel mount fused switch" | 1 | $3 |
| JST-XH kit | "JST-XH connector kit 2 3 4 pin" | 1 | $8 |
| Jumper wires | "Dupont jumper wire kit M-M M-F F-F" | 1 | $5 |
| Wire | "22 AWG stranded wire 6 color" | 1 | $8 |
| Buttons | "12mm momentary push button panel mount" (5-pack) | 1 pack | $3 |
| **Subtotal** | | | **~$52** |

## Amazon Order 2 — Mechanical (~$45)

| Item | Search Term | Qty | ~Price |
|---|---|---|---|
| GT2 belt | "GT2 timing belt 6mm 2m open loop" | 2 | $8 |
| GT2 drive pulleys | "GT2 20 tooth pulley 5mm bore 6mm" (5-pack) | 1 pack | $7 |
| GT2 idler pulleys | "GT2 20T idler pulley 5mm bore bearing" | 2 | $4 |
| 608ZZ bearings | "608ZZ bearing 8x22x7" (10-pack) | 1 pack | $6 |
| D-shaft | "5mm steel rod 100mm" or "5mm D-shaft" | 1 | $3 |
| Spring assortment | "small compression spring assortment" | 1 | $7 |
| O-rings | "silicone O-ring 20mm ID 2mm cross section" | 1 pack | $3 |
| Retard pad | "printer pickup pad rubber" or "cork rubber sheet 2mm" | 1 | $5 |
| 8mm linear rod | "8mm linear shaft 100mm hardened" (2-pack) | 1 pack | $3 |
| LM8UU bearings | "LM8UU linear bearing 8mm" (4-pack) | 1 pack | $4 |
| **Subtotal** | | | **~$50** |

## Amazon Order 3 — Fasteners (~$35)

| Item | Search Term | Qty | ~Price |
|---|---|---|---|
| M3 screw assortment | "M3 socket head cap screw assortment kit" (200-300 pcs) | 1 | $13 |
| M3x16 (NEMA17) | "M3x16 socket head cap screw" (50-pack) | 1 | $3 |
| Heat-set inserts | "M3 brass heat set insert 4mm OD 4mm length" (100-pack) | 1 | $8 |
| Heat-set tip | "soldering iron heat set insert tip M3" | 1 | $3 |
| M3 hex nuts | "M3 hex nut stainless" (100-pack) | 1 | $3 |
| M3 washers | "M3 flat washer stainless" (100-pack) | 1 | $3 |
| M3 nylock nuts | "M3 nylon lock nut" (50-pack) | 1 | $2 |
| **Subtotal** | | | **~$35** |

## Amazon Order 4 — Filament (~$62)

| Item | Search Term | Qty | ~Price |
|---|---|---|---|
| PETG | "eSUN PETG 1.75mm" or "Polymaker PolyLite PETG" | 2 kg | $40 |
| TPU 95A | "eSUN TPU 95A 1.75mm" or "NinjaTek NinjaFlex" | 1 spool (250g+) | $22 |
| **Subtotal** | | | **~$62** |

## Amazon Order 5 — Misc (~$15)

| Item | Search Term | Qty | ~Price |
|---|---|---|---|
| Rubber feet | "adhesive rubber feet 12mm" | 1 pack | $3 |
| Spiral wrap | "6mm spiral cable wrap 2m" | 1 | $3 |
| Zip ties | "100mm nylon zip ties" | 1 bag | $2 |
| Heat shrink | "heat shrink tubing assortment" | 1 | $4 |
| Hex key | "2mm ball end hex key" | 1 | $3 |
| **Subtotal** | | | **~$15** |

## Amazon Order 6 — RFID Test Kit (~$4)

| Item | Search Term | Qty | ~Price |
|---|---|---|---|
| RC522 module | "RC522 RFID module 13.56MHz SPI" | 1 | $4 |
| **Subtotal** | | | **~$4** |

## Faded Spade Order (~$15)

Order directly from fadedspade.com or Amazon:

| Item | Search Term | Qty | ~Price |
|---|---|---|---|
| RFID poker deck | "Faded Spade RFID poker cards" | 1 deck | $15 |
| **Subtotal** | | | **~$15** |

## AliExpress Order — Linear Rails (~$36)

These are the only parts worth waiting 2-3 weeks for. Amazon rails are 2-3x the price.

| Item | Search Term | Qty | ~Price |
|---|---|---|---|
| MGN12H 600mm | "MGN12H 600mm linear rail carriage" (ReliaBot or CHUANGNUO) | 2 | $18 each |
| **Subtotal** | | | **~$36** |

**When rails arrive:** remove factory grease, clean with isopropanol, re-grease with Superlube or white lithium grease. Run the carriage back and forth 20+ times to work in the new grease. Cheap rails that feel gritty will smooth out.

---

## Grand Total

| Source | Amount |
|---|---|
| Amazon orders 1-6 | ~$218 |
| Faded Spade | ~$15 |
| AliExpress | ~$36 |
| **Total** | **~$269** |

Subtract the ~$60 you already have in motors + ESP32 + drivers, and the effective BOM is **~$269 out of pocket** against the $500 ceiling. $231 headroom for iteration, spare parts, and the full RFID add-on later.

---

## Order Priority

**Order today (Amazon, arrives in 1-2 days):**
- Orders 1-5 — everything needed to start building as soon as prints are done
- Order 6 + Faded Spade — RFID test kit, can run the felt test with just the ESP32 you already have

**Order today (AliExpress, arrives in 2-3 weeks):**
- Linear rails — start printing immediately, rails arrive around the time you finish all prints

**Start printing today:**
1. Chassis section 0 (longest print, structural foundation)
2. Chassis section 1
3. Chassis section 2
4. Bin bank (may need to split into two 4-bin halves)
5. Feeder hopper
6. Everything else

See `docs/plans/print-guide.md` for per-part slicer settings.

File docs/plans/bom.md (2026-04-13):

# Single-Deck Card Shuffler V1 -- Bill of Materials

Date: 2026-04-12
Reference: `docs/plans/2026-04-09-single-deck-shuffler-design.md`
Budget ceiling: **$500** (hardware only, excludes print plastic and labor)

---

## 1. Electronics

| # | Part | Qty | Specification | Unit Cost | Source | Notes |
|---|---|-----|---|---|---|---|
| E1 | ESP32 DevKit V1 (WROOM-32) | 1 | 38-pin, dual-core 240 MHz, Wi-Fi/BLE | $7 | Amazon / AliExpress | Main controller. Plenty of GPIO for 4 motors + 6 sensors + OLED + 2 buttons. |
| E2 | TMC2209 stepper driver (BIGTREETECH or Fysetc) | 4 | UART mode, up to 2A RMS, StealthChop2 | $5 | Amazon / AliExpress | One per axis: feeder (addr 0), selector X (addr 1), recombine X (addr 2), recombine Z (addr 3). Shared UART bus on GPIO 12/13. R_sense = 0.11 ohm. |
| E3 | NEMA 17 stepper -- pancake 25mm (feeder) | 1 | 42x42x25 mm, 0.9 deg/step or 1.8 deg, >= 13 N-cm holding torque, 600 mA rated | $9 | StepperOnline 17HS08-1004S / AliExpress | Low torque OK. Needs smooth microstepping at 120 mm/s feed speed (4800 steps/s). Pancake saves space in feeder module. |
| E4 | NEMA 17 stepper -- standard 40mm (selector X) | 1 | 42x42x40 mm, 1.8 deg, >= 40 N-cm, 800 mA rated | $12 | StepperOnline 17HS16-0404S / Amazon | Moderate torque for fast positioning across 500 mm travel. Must accelerate carriage + card guide mass quickly. |
| E5 | NEMA 17 stepper -- standard 40mm (recombine X) | 1 | 42x42x40 mm, 1.8 deg, >= 40 N-cm, 800 mA rated | $12 | StepperOnline 17HS16-0404S / Amazon | Same as selector X. Traverses bin bank for pickup. |
| E6 | NEMA 17 stepper -- short 34mm (recombine Z) | 1 | 42x42x34 mm, 1.8 deg, >= 26 N-cm, 600 mA rated | $10 | StepperOnline 17HS13-0404S / AliExpress | Lower speed (2000 sps), needs holding torque for stack weight. 800 steps travel. Leadscrew or belt-driven Z. |
| E7 | SSD1306 OLED display | 1 | 0.96", 128x64, I2C (addr 0x3C) | $4 | Amazon / AliExpress | Diagnostics display. SDA = GPIO 21, SCL = GPIO 5. |
| E8 | IR reflective sensor -- TCRT5000 module | 6 | 3.3-5 V, analog/digital out, ~2-15 mm range | $1 | AliExpress (pack of 10 for ~$4) | Feed exit, post-singulation, selector throat, bin entry, recombine pickup, output checkpoint. Active-low, GPIO interrupt-capable pins (34/35/36/39/23/22). |
| E9 | 12V 10A switching power supply | 1 | 12 VDC, 120 W, IEC C14 inlet, enclosed | $14 | Amazon (Mean Well LRS-150-12 or clone) | 4 motors at 800 mA peak = 3.2A motor draw. TMC2209 + logic overhead ~2A. Total ~60W steady, 120W provides headroom for acceleration spikes. |
| E10 | 5V 3A buck converter (MP1584 or LM2596 module) | 1 | 12V in, 5V/3A out, adjustable or fixed | $3 | Amazon / AliExpress | Powers ESP32, OLED, sensors. ESP32 peak draw ~500 mA, sensors ~60 mA total, OLED ~20 mA. 3A provides margin. |
| E11 | IEC C14 panel-mount inlet + fused switch | 1 | 10A, with integrated switch and fuse holder | $3 | Amazon / AliExpress | Clean power entry to enclosure. |
| E12 | JST-XH connector kit (2/3/4 pin) | 1 kit | Assorted JST-XH male + female + crimps | $8 | Amazon | Motor, sensor, and power connectors. Allows modular wiring for service. |
| E13 | Dupont jumper wire kit | 1 kit | M-M, M-F, F-F, 10/20 cm assorted | $5 | Amazon | Prototyping and internal wiring. |
| E14 | Prototype PCB / perfboard | 2 | 5x7 cm, through-hole | $1 | AliExpress | TMC2209 carrier board, sensor breakout. |
| E15 | 22 AWG stranded wire (assorted) | 1 spool | 6 colors, ~25 ft each | $8 | Amazon | Motor and power wiring runs. |

**Electronics subtotal: ~$112**

---

## 2. Mechanical -- Motion

| # | Part | Qty | Specification | Unit Cost | Source | Notes |
|---|---|-----|---|---|---|---|
| M1 | MGN12H linear rail + carriage (selector X) | 1 | 600 mm rail, 1x MGN12H carriage block | $18 | AliExpress / Amazon | Calculated rail length ~571 mm (500.5 mm travel + 50 mm carriage + 20 mm end clearance). 600 mm is nearest standard length. |
| M2 | MGN12H linear rail + carriage (recombine X) | 1 | 600 mm rail, 1x MGN12H carriage block | $18 | AliExpress / Amazon | Rail mount plate width is 610 mm; 600 mm rail fits with motor bracket overhang. Could also use 650 mm. |
| M3 | GT2 timing belt (6mm width) | 1 | Open loop, 2 m length | $4 | Amazon / AliExpress | Cut to fit selector X (~1.4 m loop) and recombine X (~1.4 m loop). Buy 2x 2m if making separate loops. |
| M4 | GT2 timing belt (6mm width) -- spare | 1 | Open loop, 2 m length | $4 | Amazon / AliExpress | Second belt for recombine X axis. |
| M5 | GT2 20-tooth pulley (5mm bore) | 4 | 20T, 6mm belt width, 5mm bore, set screw | $2 | Amazon / AliExpress (pack of 5 ~$7) | 2 drive pulleys (on motor shafts), 2 idler positions. |
| M6 | GT2 20-tooth idler pulley (smooth, 5mm bore) | 2 | Smooth or toothed, 5mm bore, with bearing | $2 | Amazon / AliExpress | Idler end of each belt loop. Toothed preferred to prevent belt skip. |
| M7 | 608ZZ bearing | 4 | 8x22x7 mm, shielded | $1 | Amazon / AliExpress (pack of 10 ~$6) | Feeder roller shaft, idler pulleys, any free-spinning shafts. |
| M8 | 5mm D-shaft steel rod | 1 | 5mm diameter, ~100 mm length | $3 | Amazon / McMaster | Feeder roller shaft. Cut to length. |
| M9 | Compression springs (feeder pressure) | 2 | ~10 mm OD, ~20 mm free length, light rate (~0.3 N/mm) | $1 | Amazon (spring assortment) / McMaster | Retard pad pressure and hopper backstop spring loading. Exact rate tuned during bakeoff. |
| M10 | Extension spring (belt tensioner) | 2 | ~5 mm OD, ~15 mm free length | $1 | Amazon (spring assortment) | Belt tensioning for GT2 loops. |
| M11 | Silicone O-rings (feeder roller) | 10 | ~18-22 mm ID, 2-3 mm cross-section, 50A durometer | $3 | Amazon / McMaster 9452K34 | High-friction contact surface for singulation roller. Buy extras -- these are wear parts. Size depends on roller OD in final feeder design. |
| M12 | Retard pad material (cork + rubber composite) | 1 sheet | ~2 mm thick, 100x100 mm minimum | $5 | Amazon / McMaster | Cut to fit retard pad slot. Separator pad material like Canon/HP pickup pads. Alternative: 3M Bumpon material or printer pickup roller rubber. |
| M13 | Shoulder bolts (M3 thread, 5mm shoulder) | 4 | M3x8 thread, 5mm shoulder dia, 10-15 mm shoulder length | $2 | McMaster 91259A118 / Amazon | Feeder roller pivot, spring anchor points. Allows free rotation while constraining position. |
| M14 | Linear rod 8mm (recombine Z guide) | 2 | 8mm OD, ~80 mm length, hardened | $3 | Amazon / AliExpress | Z-axis vertical guide for recombine elevator. Short travel (800 steps ~20 mm). |
| M15 | LM8UU linear bearing | 2 | 8x15x24 mm | $2 | Amazon / AliExpress | Recombine Z carriage rides on 8mm rods. |

**Mechanical subtotal: ~$73**

---

## 3. Fasteners

| # | Part | Qty | Specification | Unit Cost | Source | Notes |
|---|---|-----|---|---|---|---|
| F1 | M3x6 socket head cap screw | 30 | DIN 912, stainless or black oxide | $4 | Amazon (assortment) / McMaster | OLED mount, sensor mounts, belt clamp, general assembly. |
| F2 | M3x8 socket head cap screw | 40 | DIN 912 | $5 | Amazon / McMaster | Primary assembly screw into heat-set inserts (4 mm insert depth + clearance). |
| F3 | M3x10 socket head cap screw | 20 | DIN 912 | $3 | Amazon / McMaster | Deeper assemblies, motor mounts through brackets. |
| F4 | M3x16 socket head cap screw | 16 | DIN 912 | $3 | Amazon / McMaster | NEMA17 mounting (4 per motor x 4 motors). Standard NEMA17 mounting depth. |
| F5 | M3x20 socket head cap screw | 8 | DIN 912 | $2 | Amazon / McMaster | Long reach through thicker printed parts or stacked assemblies. |
| F6 | M4x10 socket head cap screw | 8 | DIN 912 | $2 | McMaster / Amazon | MGN12H rail mounting to chassis (M3 holes on carriage, but M4 may be used for rail-to-frame). |
| F7 | M3 brass heat-set insert (short) | 50 | M3x4x4 mm (OD 4.0, length 4.0), knurled | $6 | Amazon (CNC Kitchen style) / AliExpress | Counted from CAD: bin bank 4, recombine rail plate 4, output tray 4, selector carriage + motor mounts ~8, feeder module ~8, electronics bay ~6, chassis frame ~16. Total ~50, buy extra. |
| F8 | M3 hex nut | 20 | DIN 934, stainless | $2 | Amazon / McMaster | Belt clamp bolts, adjustable assemblies where inserts don't apply. |
| F9 | M3 flat washer | 30 | DIN 125, stainless | $2 | Amazon / McMaster | Under screw heads on clearance holes, spring retention. |
| F10 | M3 lock washer or Nylock nut | 10 | Split lock washer or M3 Nylock | $1 | Amazon / McMaster | Vibration-prone joints (motor mounts). |
| F11 | M3 brass heat-set insert (short) -- spare bag | 50 | Same as F7 | $6 | Amazon / AliExpress | Reprints and mistakes. 100 total is a comfortable stock for iteration. |

**Fasteners subtotal: ~$36**

Recommended: buy an M3 socket cap screw assortment kit (M3 x 4/6/8/10/12/16/20 mm, ~200 pcs) for ~$12-15 from Amazon. Covers F1-F5 and provides spares.

---

## 4. 3D Printed Parts

| # | Part | Qty | Material | Est. Weight | Notes |
|---|---|-----|---|---|---|
| P1 | Feeder hopper + base | 1 | PETG | ~120 g | Inclined hopper with side rails, throat, motor mount pocket. Largest single print. |
| P2 | Feeder roller (with O-ring grooves) | 1 | PETG | ~15 g | Precision bore for 5mm D-shaft. O-ring grooves for silicone friction surface. |
| P3 | Retard pad holder | 1 | PETG | ~8 g | Spring-loaded, replaceable pad slot. Wear part -- design for easy swap. |
| P4 | Selector carriage + card guide | 1 | PETG | ~45 g | Rides on MGN12H, belt clamp integrated. Card channel with entry funnel. |
| P5 | Selector motor mount bracket | 1 | PETG | ~30 g | End plate for NEMA17 at -X end of selector rail. |
| P6 | Selector idler bracket | 1 | PETG | ~20 g | Opposite end bracket with idler pulley mount. |
| P7 | Bin bank (8 bins) | 1-2 | PETG | ~250 g | May print as two 4-bin halves if bed is < 570 mm (likely). Entry funnels, smooth internal finish. Largest assembly. |
| P8 | Recombine X carriage + pickup head | 1 | PETG | ~50 g | MGN12H mount, Z-axis guide mounts, belt clamp. |
| P9 | Recombine rail mount plate | 1 | PETG | ~60 g | ~610x43 mm plate. Will need to print diagonally or in sections on standard 256 mm bed. |
| P10 | Recombine Z elevator bracket | 1 | PETG | ~25 g | Linear bearing holders, motor mount for Z stepper. |
| P11 | Recombine motor mount bracket (X) | 1 | PETG | ~30 g | NEMA17 end plate for recombine X axis. |
| P12 | Recombine Z motor mount | 1 | PETG | ~20 g | NEMA17 mount for Z leadscrew/belt drive. |
| P13 | Output tray | 1 | PETG | ~80 g | Card pocket with side guides, 4x chassis mount inserts. |
| P14 | Electronics bay / tray | 1 | PETG | ~40 g | Holds ESP32, TMC2209 boards, buck converter. Ventilation slots. |
| P15 | Chassis base frame | 2-4 | PETG | ~200 g | Structural base, printed in sections. Receives all module mounts via heat-set inserts. |
| P16 | Enclosure panels (top, sides) | 4-6 | PETG | ~180 g | Optional for V1. Can defer to open-frame for debug. |
| P17 | Feeder roller sleeve | 1 | TPU 95A | ~5 g | Alternative to O-rings: full TPU sleeve press-fit over roller for higher friction. |
| P18 | Output tray bumpers | 2 | TPU 95A | ~3 g | Soft landing pads for card stack squaring. |
| P19 | Sensor mount clips | 6 | PETG | ~12 g | Snap-fit or screw-on brackets for TCRT5000 modules at each checkpoint. |
| P20 | Belt tensioner blocks | 2 | PETG | ~10 g | Spring-loaded idler adjustment for GT2 belts. |
| P21 | Cable clips / guides | 6 | PETG | ~8 g | Snap-on wire management along frame. |

| | | | **PETG total** | **~1,200 g** | |
| | | | **TPU total** | **~8 g** | |

| # | Material | Qty | Specification | Unit Cost | Source | Notes |
|---|---|-----|---|---|---|---|
| P-MAT1 | PETG filament | 2 kg | 1.75 mm, any color | $20/kg | Amazon (Hatchbox, eSUN, Polymaker) | ~1.2 kg estimated usage + waste/supports/reprints. 2 kg provides margin. |
| P-MAT2 | TPU filament (95A) | 0.25 kg | 1.75 mm, 95A Shore | $22 | Amazon (NinjaTek, eSUN) | Small usage but need a full spool. Could substitute O-rings (M11) for roller instead. |

**3D print material subtotal: ~$62**

---

## 5. Miscellaneous

| # | Part | Qty | Specification | Unit Cost | Source | Notes |
|---|---|-----|---|---|---|---|
| X1 | Tactile push button (panel mount, 12mm) | 2 | Momentary, normally-open, panel mount | $2 | Amazon / AliExpress | Shuffle button (GPIO 15) and Stop/Clear Jam button (GPIO 0). Internal pull-up. |
| X2 | Rubber feet (adhesive) | 4 | ~12 mm dia, ~6 mm height, adhesive backed | $3 | Amazon | Anti-vibration, non-slip base. |
| X3 | Cable sleeve / spiral wrap | 1 | 6 mm dia, 2 m length | $3 | Amazon | Wiring harness management for motor and sensor cables. |
| X4 | Zip ties (small) | 1 bag | 100 mm, nylon, assorted | $2 | Amazon | Cable management. |
| X5 | Heat shrink tubing assortment | 1 kit | 2:1 ratio, assorted diameters | $4 | Amazon | Solder joint insulation on sensor and power wiring. |
| X6 | M3 hex key (2.0 mm) | 1 | Ball-end preferred | $3 | Amazon | Service tool. L-key or T-handle. |
| X7 | Soldering iron with fine tip (if not owned) | -- | -- | -- | -- | Required for heat-set inserts and wiring. Assumed already owned. |

**Miscellaneous subtotal: ~$17**

---

## Cost Summary

| Category | Subtotal |
|---|---|
| Electronics | $112 |
| Mechanical -- Motion | $73 |
| Fasteners | $36 |
| 3D Print Material | $62 |
| Miscellaneous | $17 |
| **Total** | **$300** |

**Margin to $500 ceiling: $200 (40%)**

---

## Budget Headroom Allocation

Per the design document, the ~$200 headroom is intended for:

| Use | Est. Cost | Notes |
|-----|---|---|
| Sensor upgrade: Omron B5W-LB2101 (replace TCRT5000 at critical positions) | $30 | Better focused beam, more reliable at 3-5 mm range. Use at feed exit and post-singulation; keep TCRT5000 at lower-risk positions. |
| Second ESP32 for logging / debug | $7 | Dedicated serial logger without interfering with control loop timing. |
| Vacuum pickup prototype parts (feeder bakeoff candidate) | $40 | Small vacuum pump, tubing, suction cups for candidate C evaluation. |
| Spare stepper motor | $12 | One extra standard NEMA17 in case of DOA or damage during assembly. |
| Spare TMC2209 drivers | $10 | Two extra drivers. These are fragile -- easy to fry during wiring. |
| Extra MGN12H carriage blocks | $12 | One spare per rail in case of binding or damage. |
| Upgraded belt (Gates PowerGrip GT2) | $10 | Higher quality belt if AliExpress GT2 has pitch accuracy issues. |
| Contingency | $79 | Unexpected parts, reprints, wrong sizes, shipping. |
| **Headroom total** | **$200** | |

---

## Ordering Notes

1. **AliExpress vs Amazon tradeoff**: AliExpress prices are 30-50% lower on motors, drivers, rails, and sensors, but shipping is 2-4 weeks. Amazon is 1-2 day delivery at higher cost. Prices above assume a mix. For fastest start, order everything from Amazon and expect ~$350-380 total.

2. **Linear rails**: buy from a reputable AliExpress seller (Hiwin clones from ReliaBot, CHUANGNUO, or similar). Cheap rails with poor ball recirculation will bind. Inspect and re-grease on arrival.

3. **TMC2209 wiring caution**: the UART daisy-chain requires correct MS1/MS2 pin configuration for addresses 0-3. Verify the breakout board pinout matches BIGTREETECH or Fysetc documentation before wiring.

4. **NEMA17 motor selection**: the feeder motor (E3) can be a cheaper pancake stepper because it runs at low current (600 mA) and moderate speed. The X-axis motors (E4, E5) need full-size 40 mm bodies for the torque to accelerate carriage mass at 4000 steps/s. The Z motor (E6) is intermediate.

5. **Fastener assortment**: a single M3 SHCS assortment kit (~$13) is more economical than buying individual lengths. Supplement with the specific M3x16 pack for NEMA17 mounting.

6. **Heat-set inserts**: buy 100 (two bags of 50). The CNC Kitchen / Ruthex M3x4x4 style is the standard for 3D printing. A soldering iron with a dedicated insertion tip ($8) makes installation much easier.

7. **Bin bank print strategy**: at 570 mm wide, the bin bank exceeds most printer beds. Plan to print as two 4-bin halves with a tongue-and-groove or dowel pin alignment joint, bolted together with M3 screws.

8. **Recombine rail mount plate**: at 610 mm, this also exceeds standard beds. Print in 2-3 sections and join with embedded M3 hardware or print diagonally on a 300+ mm bed (Ender 5 Plus, CR-10, Voron 350).

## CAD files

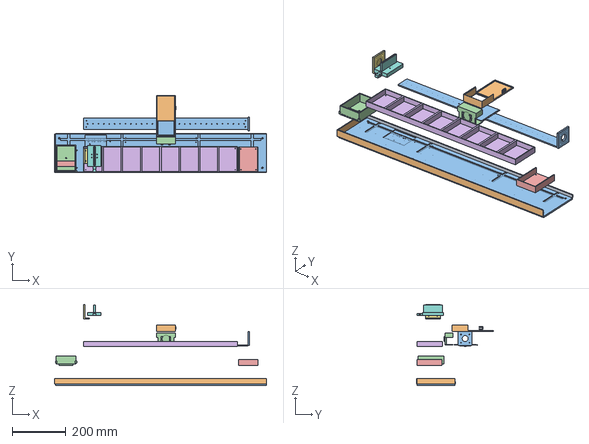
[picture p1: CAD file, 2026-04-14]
cad/renders/assembly_exploded.step
786.0 x 287.2 x 300.8 mm

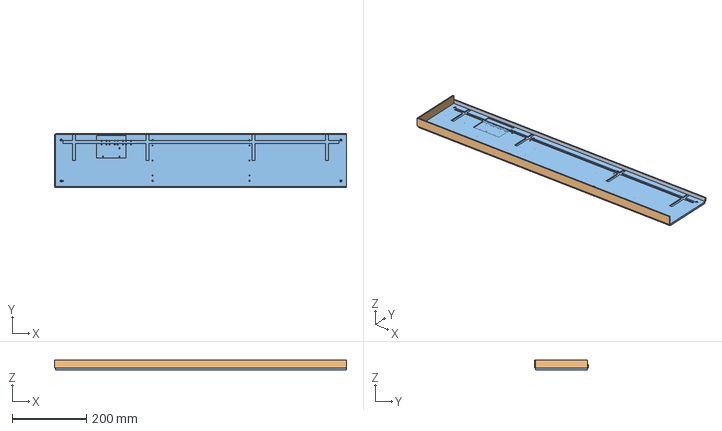
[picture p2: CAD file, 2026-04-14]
cad/chassis/chassis_full.step
786.0 x 146.0 x 27.0 mm

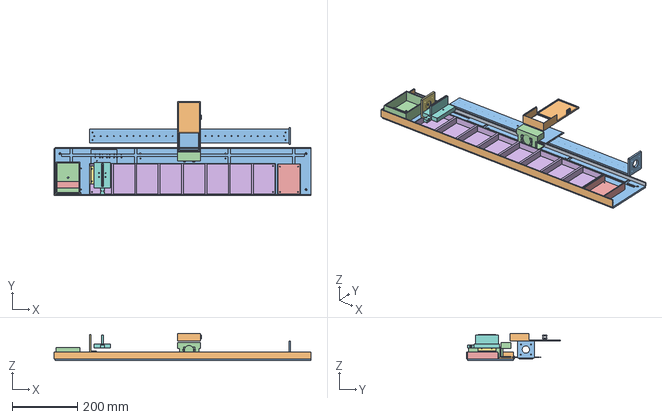
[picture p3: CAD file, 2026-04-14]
cad/renders/assembly_full.step
786.0 x 287.2 x 84.0 mm

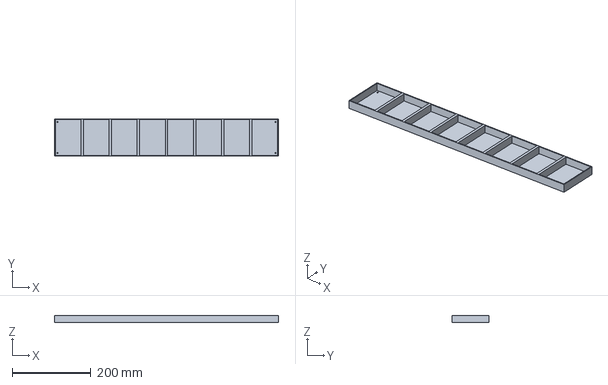
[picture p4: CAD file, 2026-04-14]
cad/bin-bank/bin_bank.step
570.0 x 94.9 x 18.5 mm

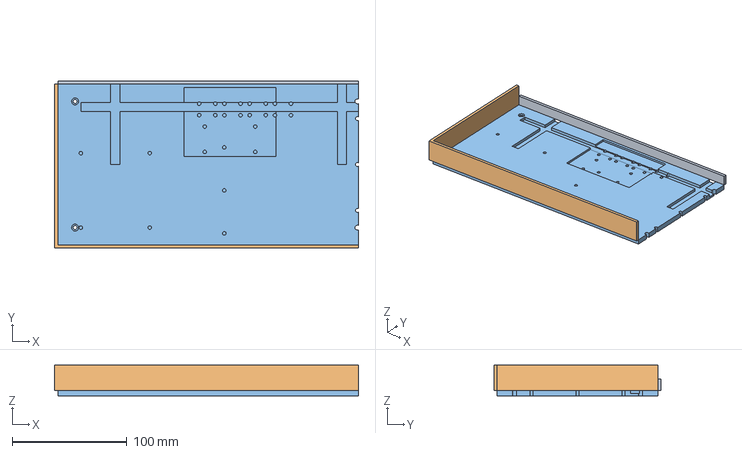
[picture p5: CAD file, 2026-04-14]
cad/chassis/chassis_section_0.step
265.0 x 146.0 x 27.0 mm

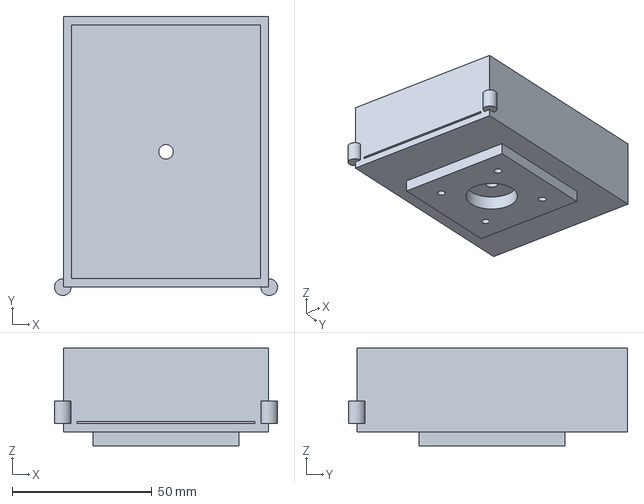
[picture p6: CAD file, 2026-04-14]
cad/feeder/feeder.step
79.9 x 99.9 x 35.0 mm

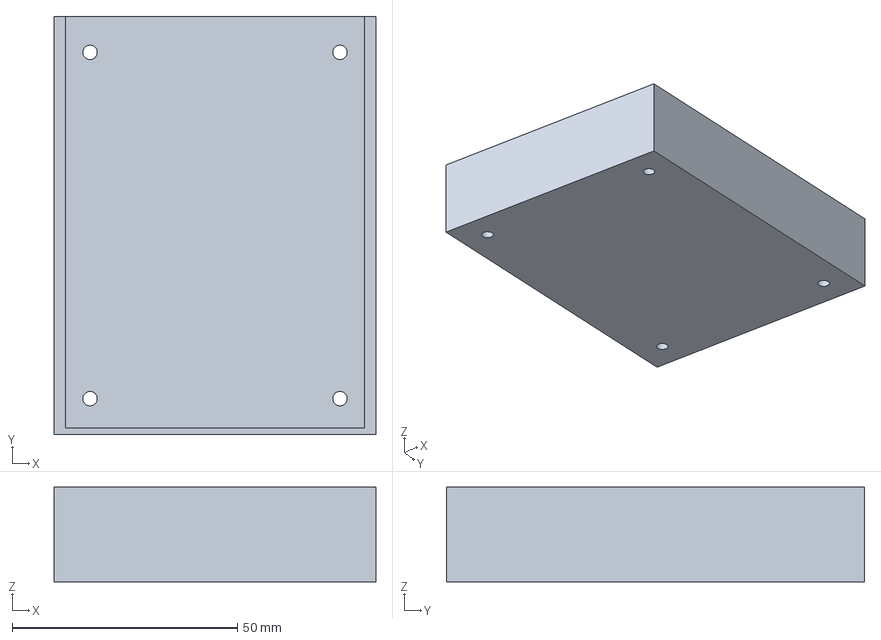
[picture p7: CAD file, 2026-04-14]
cad/output/output.step
71.5 x 92.9 x 21.0 mm

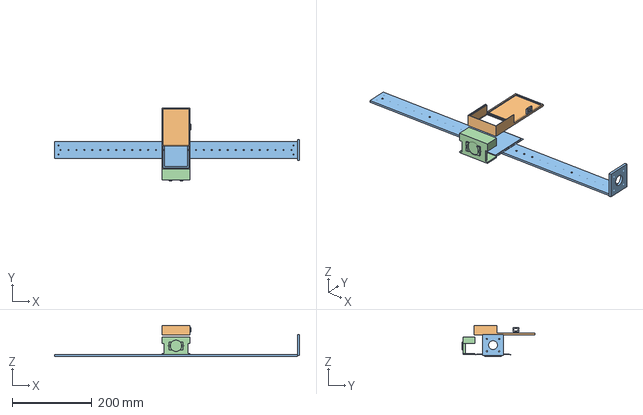
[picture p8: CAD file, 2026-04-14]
cad/recombine/recombine.step
615.0 x 184.4 x 79.0 mm

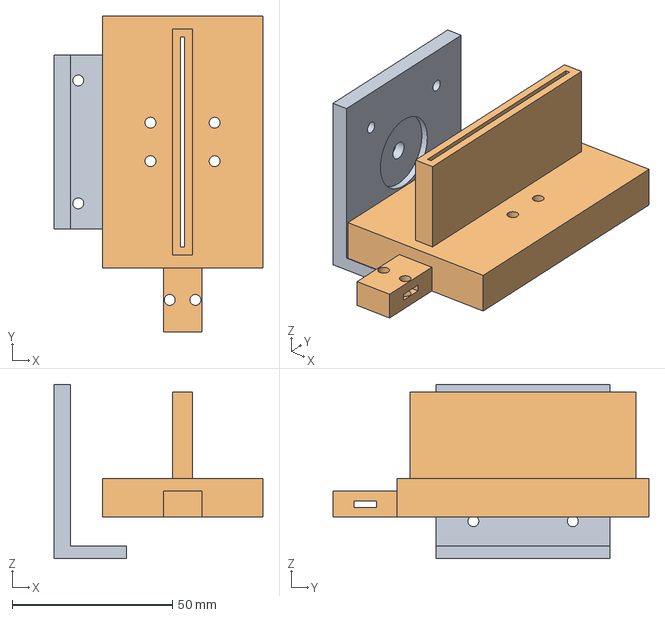
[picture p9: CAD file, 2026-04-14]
cad/selector/selector.step
65.0 x 98.5 x 54.3 mm

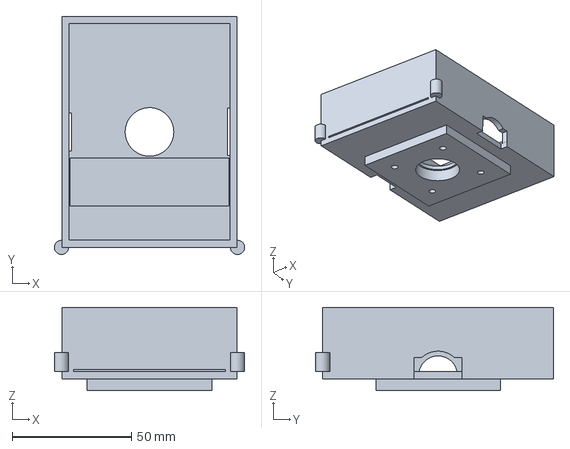
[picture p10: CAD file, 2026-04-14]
cad/feeder/feeder_candidate_a.step
79.9 x 99.9 x 35.0 mm

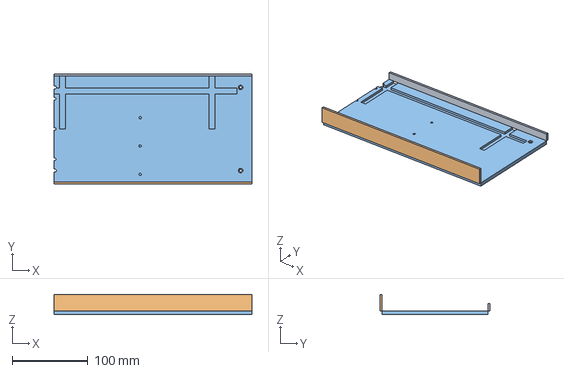
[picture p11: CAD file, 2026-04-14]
cad/chassis/chassis_section_2.step
262.0 x 146.0 x 27.0 mm

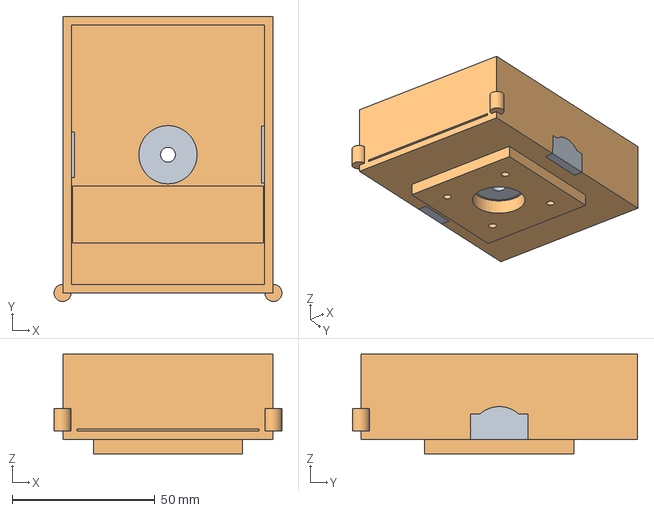
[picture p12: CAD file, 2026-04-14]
cad/renders/feeder_detail.step
79.9 x 99.9 x 35.0 mm

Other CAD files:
cad/chassis/chassis_section_1.step
cad/renders/bin_bank_detail.step
cad/bin-bank/bin_bank.stl
cad/chassis/chassis_full.stl
cad/chassis/chassis_section_0.stl
cad/chassis/chassis_section_1.stl
cad/chassis/chassis_section_2.stl
cad/feeder/feeder.stl
cad/feeder/feeder_candidate_a.stl
cad/output/output.stl
cad/recombine/recombine.stl
cad/selector/selector.stl

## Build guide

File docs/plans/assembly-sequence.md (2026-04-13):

# Assembly Sequence -- Single-Deck Card Shuffler V1

Date: 2026-04-12
Reference: `docs/plans/bom.md`, `docs/plans/print-guide.md`, `docs/plans/datum-tolerance-budget.md`

---

## Prerequisites

### All Printed Parts Ready

Before starting assembly, every printed part from the print guide must be complete with post-processing done:

- [ ] Chassis sections 0, 1, 2 (P15) -- heat-set inserts installed, dowel bores reamed, base plate sanded
- [ ] Bin bank sections (P7) -- interior walls sanded, heat-set inserts in base
- [ ] Feeder hopper (P1) -- bearing bores reamed, supports removed, heat-set inserts installed
- [ ] Feeder roller (P2) -- D-shaft bore reamed
- [ ] Retard pad holder (P3) -- pivot bore reamed, retard pad material glued in
- [ ] Selector carriage (P4) -- guide channel sanded
- [ ] Selector motor mount (P5) and idler bracket (P6)
- [ ] Recombine carriage (P8), rail plate (P9), Z elevator (P10), motor mounts (P11, P12)
- [ ] Output tray (P13) -- heat-set inserts installed
- [ ] Electronics bay (P14) -- heat-set inserts installed
- [ ] Sensor clips (P19), belt tensioners (P20), cable clips (P21)
- [ ] TPU roller sleeve (P17) and bumpers (P18)

### All BOM Items Received

Cross-reference `bom.md`. Key items to verify before starting:

- [ ] ESP32 DevKit V1 (E1) -- verify it powers on via USB and serial monitor works
- [ ] 4x TMC2209 driver boards (E2) -- verify all 4 have correct MS1/MS2 pads for addresses 0-3
- [ ] 4x NEMA17 steppers (Lumen 3D printer salvage, all 40mm standard — see `motor-setup-lumen.md`)
- [ ] 2x MGN12H rail + carriage sets, 600 mm (M1, M2)
- [ ] GT2 belts 2x 2m (M3, M4), 4 drive pulleys (M5), 2 idler pulleys (M6)
- [ ] 4x 608ZZ bearings (M7) or 625ZZ as specified in feeder CAD
- [ ] 5 mm D-shaft (M8)
- [ ] Compression springs (M9), extension springs for tensioners (M10)
- [ ] Silicone O-rings (M11) or TPU roller sleeve (P17)
- [ ] Retard pad material (M12)
- [ ] Shoulder bolts (M13)
- [ ] 2x 8 mm linear rods (M14), 2x LM8UU bearings (M15)
- [ ] Full fastener assortment: M3x6 through M3x20 SHCS, M3 hex nuts, washers, lock washers
- [ ] M3 brass heat-set inserts (100 pcs total, ~50 already installed in printed parts)
- [ ] 6x TCRT5000 IR sensors (E8)
- [ ] OLED display (E7)
- [ ] 12V PSU (E9), 5V buck converter (E10), IEC inlet (E11)
- [ ] JST-XH connectors (E12), wire (E15)
- [ ] Buttons (X1), rubber feet (X2)

### Tools Needed

- 2.0 mm hex key (M3 socket cap screws) -- ball-end preferred
- 2.5 mm hex key (M4 if used)
- Soldering iron with fine tip (for heat-set inserts, already done, and wiring)
- Heat-set insert installation tip (dedicated tip for soldering iron, or use a flat tip carefully)
- Digital calipers
- Multimeter
- Feeler gauge set (0.05 mm increments, for nip gap adjustment)
- Small Phillips screwdriver (for some sensor modules)
- Wire strippers, crimping tool for JST-XH
- USB cable (micro or Type-C depending on your ESP32 DevKit variant)
- Computer with PlatformIO or Arduino IDE installed
- Deck of playing cards (poker size, 52 cards) for testing
- Small level or straightedge (~300 mm)
- Needle files, 320-grit sandpaper
- CA glue (thin viscosity)
- Threadlocker (blue Loctite 242) -- optional but recommended for motor mount screws

---

## Assembly Sequence

### Phase 1: Chassis Frame

Everything mounts to the chassis, so assemble it first and verify datum surfaces.

#### Step 1.1: Join Chassis Sections

**Parts:** Chassis sections 0, 1, 2, 4x M4 dowel pins, 6x M3x10 bolts, 6x M3 nuts

1. Lay all three sections on a flat surface (glass, granite tile, or machine table) with the base plate face down (side rail facing up).
2. Insert two 4.0 mm dowel pins into the bores at the Split 1 joint (between sections 0 and 1). Pins should protrude ~8 mm from each face.
3. Slide section 1 onto the pins until the faces mate. The joint should close with minimal gap (< 0.3 mm).
4. Insert the 3x M3x10 bolts through the joint bolt holes from the bottom (base plate side) and thread M3 nuts on top. Tighten evenly.
5. Repeat for the Split 2 joint (sections 1 and 2).
6. Flip the assembled chassis right-side up. Check:
   - The side rail (Datum B) forms a continuous straight line. Sight along it -- no steps at the joints.
   - The base plate is flat. Set it on your flat surface and check for rocking. Shim under the joints if needed.
   - Measure overall length: should be ~785 mm (CHASSIS_LENGTH).

#### Step 1.2: Install Rubber Feet

**Parts:** 4x rubber feet (X2), 4x M3x8 bolts

1. Flip the chassis upside down.
2. Insert an M3x8 bolt through each corner foot hole (15 mm inset from each edge).
3. Place a rubber foot over each bolt and secure. The feet provide vibration isolation and prevent the machine from walking during operation.
4. Flip right-side up. The chassis should sit level and stable.

#### Step 1.3: Verify Datum Surfaces

Before mounting anything, confirm the three datum surfaces:

- **Datum A (base plate top):** Run your finger along it. It should be smooth and flat. If any section joints have a Z-step, sand the high side flush.
- **Datum B (side rail inner face):** Lay a straightedge along the full length. Maximum deviation: 0.3 mm. This is the lateral reference for every module.
- **Datum C (feeder end stop inner face):** Verify it is perpendicular to Datum B with a small square.

---

### Phase 2: Linear Rails

Install the linear rails early because other modules mount to or reference the rail carriages. Rails are easier to align before the chassis is crowded with parts.

#### Step 2.1: Selector Rail (MGN12H, 600 mm)

**Parts:** 600 mm MGN12H rail + carriage (M1), M3x6 bolts (quantity depends on rail hole count, typically 15-20)

1. The selector rail mounts alongside the bin bank zone on the chassis base plate. The rail runs parallel to Datum B along the X axis.
2. Loosely position the rail in the selector mounting area (X = 105 mm to X = 675 mm, the bin bank zone).
3. Insert M3x6 bolts through the rail's mounting holes into the chassis heat-set inserts. Start from the center and work outward. Finger-tighten only.
4. Push the rail against a straight reference (a steel ruler clamped along Datum B works well) to ensure it is parallel to the side rail. The rail-to-Datum-B distance must be consistent along its length to within 0.2 mm.
5. Tighten all bolts evenly, working from center outward. Do not overtorque -- the heat-set inserts will pull out of PETG if you exceed ~0.5 N-m.
6. Slide the carriage block back and forth by hand. It should glide smoothly with no binding. If it binds at any point, loosen the bolts in that area, re-align, and re-tighten.

#### Step 2.2: Recombine Rail (MGN12H, 600 mm)

**Parts:** 600 mm MGN12H rail + carriage (M2), M3x6 bolts

1. Mount the recombine rail to the recombine rail mount plate (P9) first, not directly to the chassis. Follow the same center-out bolt pattern.
2. Verify carriage motion across the full plate length.
3. Set the rail plate assembly aside -- it will be installed on the chassis after the bin bank.

---

### Phase 3: Bin Bank

The bin bank is the largest module and sets the physical positions of all 8 bins. The selector and recombine modules both reference the bin positions.

#### Step 3.1: Assemble Bin Bank Sections

**Parts:** Bin bank sections (P7), 4.0 mm dowel pins, M3x8 bolts, M3 nuts (for inter-section joints)

If printed as 4 quarters:
1. Join the 4 sections using dowel pins and bolts at each joint, same procedure as the chassis joints.
2. Verify bin-to-bin pitch by measuring center-to-center distance across several bin pairs. Nominal: 71.5 mm. Record the actual positions -- you will enter these as calibration values in firmware later.
3. Check internal bin dimensions: 65.5 mm width x 90.9 mm depth. Drop a card into each bin to verify free fit.

#### Step 3.2: Mount Bin Bank to Chassis

**Parts:** Assembled bin bank, M3x8 bolts, M3 washers

1. The bin bank sits in the bin bank zone (X = 105 to X = 675 mm) on the chassis base plate.
2. Push the bin bank's left edge (the side that will face the cards) against Datum B (side rail). This registers the bin bank laterally.
3. Insert M3x8 bolts through the bin bank's base clearance holes into the chassis heat-set inserts. The bin bank has slotted holes for X adjustment -- center the bolts in the slots for now.
4. Tighten all mounting bolts.
5. Verify: drop a card into each of the 8 bins. Every card should fall freely to the bin floor and sit flat.

---

### Phase 4: Feeder Module

The feeder is the most precision-critical module. Take your time here.

#### Step 4.1: Install Bearings and Shaft

**Parts:** Feeder hopper (P1), 2x 625ZZ bearings (or 608ZZ per BOM -- match to your CAD), 5 mm D-shaft (M8), O-rings (M11) or TPU sleeve (P17)

1. Press one 625ZZ bearing into the left side wall bore of the feeder hopper. It should be a firm press-fit. If it is too tight, ream the bore slightly and retry. If it is loose, use a drop of retaining compound (Loctite 638) or thin CA glue.
2. If using an eccentric bushing on the right side, install the bushing into the oversized right-side bore first, then press the second bearing into the bushing. If not using a bushing, press the second bearing directly.
3. Slide the 5 mm D-shaft through both bearings. Spin it -- it should rotate freely with no perceptible wobble.
4. Install the feeder roller (P2) onto the shaft. The D-flat prevents rotation. If using a TPU sleeve (P17), stretch it over the roller now. If using O-rings (M11), seat them in the roller grooves.
5. Verify the roller protrudes approximately 1.0 mm above the hopper floor surface. This is the drive contact point for the bottom card.

#### Step 4.2: Install Retard Pad Assembly

**Parts:** Retard pad holder (P3), 2x shoulder bolts (M13), 1x compression spring (M9)

1. Slide the retard pad holder into the dovetail channel from the right side of the hopper.
2. Insert the shoulder bolts through the side wall holes and through the holder's pivot bores. The holder should pivot freely on the shoulder bolts.
3. Insert the compression spring into the spring pocket behind the retard pad.
4. Thread the M3 set screw into the rear wall hole until it just contacts the spring. This controls the nip pressure.

#### Step 4.3: Set the Nip Gap

**Critical adjustment.** The gap between the roller surface and the retard pad determines whether the feeder singulates one card at a time.

1. With no cards in the hopper, rotate the roller by hand and observe the retard pad contact point.
2. Insert a 0.30 mm feeler gauge between the roller and the retard pad. It should slide through with light resistance.
3. Insert a 0.60 mm feeler gauge. It should NOT pass through (this would allow doubles).
4. Adjust the set screw to tune spring preload until the gap is in the 0.30-0.40 mm range.
5. If using an eccentric bushing, rotate it to fine-tune the roller height, then lock it with a set screw or friction fit.

#### Step 4.4: Mount NEMA17 Pancake Stepper (Feeder)

**Parts:** NEMA17 pancake stepper (E3), 4x M3x16 bolts

1. The motor mounts to the bottom of the feeder hopper on the mounting plate.
2. Slide the motor shaft through the pilot hole and into the roller shaft coupling (or the D-shaft bore if direct-drive).
3. Align the motor so the shaft engages the roller correctly.
4. Insert 4x M3x16 bolts through the mounting plate into the motor's threaded holes. Apply a drop of threadlocker to each bolt.
5. Tighten in a cross pattern.
6. Spin the motor shaft by hand. The roller should spin smoothly and the retard pad should deflect slightly when a card-thickness object passes through the nip.

#### Step 4.5: Mount Feeder to Chassis

**Parts:** Assembled feeder, M3x8 bolts

1. Place the feeder at the X = 0 end of the chassis, butting the back of the hopper against Datum C (feeder end stop).
2. Push the left side of the feeder against Datum B (side rail).
3. Bolt down through the feeder's base into the chassis heat-set inserts (4 locations). These are fixed holes (not slotted) because the feeder references Datum C directly.
4. Verify: the exit throat is clear, aligned with where the selector will be, and at the correct height above Datum A.

---

### Phase 5: Selector Module

#### Step 5.1: Assemble Selector Carriage onto Rail

**Parts:** Selector carriage (P4)

1. The MGN12H carriage block should already be on the selector rail (installed in Step 2.1).
2. Bolt the selector carriage (P4) onto the carriage block using 4x M3x8 bolts through the carriage's base plate into the block's threaded holes.
3. Slide the assembly back and forth by hand. The carriage should glide smoothly and the card guide channel should remain vertical (not tilting).

#### Step 5.2: Install Selector Motor Mount and Idler

**Parts:** Motor mount bracket (P5), idler bracket (P6), NEMA17 standard stepper (E4), GT2 20T drive pulley (M5), GT2 idler pulley (M6), 4x M3x16 bolts (motor), M3x8 bolts (bracket mounting)

1. Mount the NEMA17 stepper to the motor mount bracket (P5) using 4x M3x16 bolts. Apply threadlocker.
2. Press the GT2 20T drive pulley onto the motor shaft, teeth facing the rail. Tighten the set screw against the D-flat.
3. Bolt the motor mount bracket to the chassis at the -X end of the selector rail. Use slotted holes for X adjustment. Leave slightly loose.
4. Mount the idler bracket at the +X end of the rail. Install the idler pulley on a 5 mm shoulder bolt or shaft with a bearing.

#### Step 5.3: Install GT2 Belt (Selector)

**Parts:** GT2 belt (M3), belt tensioner block (P20), extension spring (M10)

1. Thread the GT2 belt around the drive pulley, along the rail, around the idler pulley, and back.
2. Clamp both belt ends into the belt clamp on the selector carriage (P4). Thread the belt through the clamp slot and tighten the 2x M3 clamp bolts.
3. Install the belt tensioner if needed -- a spring-loaded idler that keeps constant tension.
4. Check belt tension: press the belt midspan with a finger. It should deflect 2-3 mm with moderate pressure, then spring back. Too loose causes skipped teeth; too tight causes motor stall and premature bearing wear.

#### Step 5.4: Align Selector to Feeder Exit

1. Manually position the selector carriage at the feeder end (bin 0 position).
2. Check the alignment between the feeder exit throat and the selector card guide entry:
   - **Lateral (Y):** The guide channels should be co-linear. The card must pass from the feeder exit into the selector guide without hitting a wall edge. Adjust the selector mounting bolts in their slotted holes if needed.
   - **Vertical (Z):** The selector guide entry should be at the same height or slightly lower (up to 0.5 mm) than the feeder exit. A downward step is acceptable; an upward step will catch cards. Use shims under the selector rail if the Z step is wrong.
   - **Entry chamfer:** The selector guide has a 3 mm flared entry. Verify by sliding a card from the feeder exit path into the selector guide by hand. It should enter smoothly.
3. Once aligned, tighten all mounting bolts.

---

### Phase 6: Recombine Module

#### Step 6.1: Assemble Recombine Z Elevator

**Parts:** Z elevator bracket (P10), 2x 8 mm linear rods (M14), 2x LM8UU bearings (M15), pusher plate (from P8), Z motor mount (P12), NEMA17 short stepper (E6) or 28BYJ-48

1. Press the LM8UU linear bearings into the elevator bracket bores.
2. Slide the 8 mm rods through the bearings. The rods should move smoothly vertically.
3. Attach the pusher plate to the linear bearing carriage.
4. Verify the pusher plate travels smoothly through the full elevator range (0 to ~25 mm).
5. Mount the Z-axis stepper to the Z motor mount (P12) and connect it to the elevator mechanism (belt, leadscrew, or rack-and-pinion depending on your implementation).

#### Step 6.2: Assemble Recombine X Carriage

**Parts:** Recombine X carriage (P8), the Z elevator sub-assembly from Step 6.1, collection tray (part of recombine)

1. Bolt the recombine carriage (P8) onto the MGN12H carriage block on the recombine rail plate (assembled in Step 2.2).
2. Mount the Z elevator sub-assembly onto the X carriage.
3. Attach the collection/accumulator tray above the elevator.
4. Slide the assembly along the rail. Verify it travels the full bin bank width without interference.

#### Step 6.3: Install Recombine Motor Mount and Belt

**Parts:** Recombine motor mount bracket (P11), NEMA17 standard stepper (E5), GT2 pulley (M5), idler pulley (M6), GT2 belt (M4), belt tensioner (P20), extension spring (M10)

1. Same procedure as the selector belt installation (Steps 5.2 and 5.3), but for the recombine rail.
2. Mount the motor bracket at one end of the rail plate.
3. Thread and tension the belt. Clamp to the carriage.

#### Step 6.4: Mount Recombine Rail Plate to Chassis

**Parts:** Assembled recombine rail plate with carriage, M3x8 bolts

1. Position the rail plate assembly below/behind the bin bank (in the recombine zone on the chassis).
2. Bolt down using slotted holes for X adjustment. Align so the pusher plate can reach the center of each bin cavity when the X carriage is at the corresponding bin position.
3. Test: move the X carriage to each of the 8 bin positions. At each position, the pusher plate should align with the bin floor slot (if using bottom-push extraction). Adjust X position of the rail plate as needed.

#### Step 6.5: Squaring Station

**Parts:** Squaring station (integrated into recombine part), solenoid or tap arm mechanism

1. The squaring station is positioned after the accumulator tray in the card path. Verify the tight pocket dimensions: 64.5 mm width (card width + 0.5 mm per side clearance).
2. Mount the solenoid or tap-arm mechanism to the external boss on the squaring station. Wire to a JST-XH connector (leave wiring for Phase 8).
3. Test by manually placing a small stack of cards into the squaring station funnel. They should settle into the tight pocket and sit square.

---

### Phase 7: Output Tray

#### Step 7.1: Mount Output Tray

**Parts:** Output tray (P13), TPU bumpers (P18), 4x M3x8 bolts

1. Press or glue the TPU bumpers into the output tray.
2. Position the output tray at the far end of the chassis (X = 680 to X = 780 mm, the output zone).
3. Push the tray against Datum B.
4. Bolt down using slotted holes for X adjustment. The output tray has generous internal dimensions, so precise alignment is not critical.

#### Step 7.2: Verify Card Path

At this point, the full mechanical card path is assembled. Walk through it manually:

1. Place a card in the feeder hopper.
2. Manually rotate the feeder roller. The card should feed through the exit throat.
3. Manually guide the card from the feeder exit into the selector guide.
4. With the selector over bin 0, release the card. It should drop through the guide, through the funnel, and land flat in the bin.
5. Repeat for bins 1-7 by moving the selector carriage by hand.
6. Test the recombine pickup: manually raise the pusher plate through a bin floor slot. It should lift the card(s).
7. Test the squaring station: manually transfer a small stack into the squaring station funnel.
8. Test the output: manually place a deck in the output tray. It should sit square and be easy to pick up from the open front.

Fix any alignment issues, binding, or card-catching problems NOW before wiring electronics.

---

### Phase 8: Electronics and Wiring

#### Step 8.1: Power Distribution

**Parts:** 12V PSU (E9), IEC inlet + fused switch (E11), 5V buck converter (E10), wire (E15), connectors (E12)

1. Mount the IEC inlet panel connector in your enclosure panel or a dedicated bracket on the chassis.
2. Wire the IEC inlet hot and neutral through the fused switch to the 12V PSU input terminals. Connect earth ground to the PSU ground terminal and to the chassis (if metal parts are present; for all-plastic V1, ground to the PSU enclosure).
3. Mount the 12V PSU. It can sit in the electronics bay area or externally.
4. Wire the 12V PSU output to:
   - A distribution bus with 4 branches for the TMC2209 driver boards (VM / motor power).
   - The 5V buck converter input.
5. Adjust the buck converter output to 5.0V using a multimeter. Verify under no-load.
6. Wire the buck converter 5V output to:
   - ESP32 DevKit VIN pin (or 5V pin, depending on your board revision).
   - OLED display VCC.
   - TCRT5000 sensor modules VCC.

**Test checkpoint:** Power on the system. The ESP32 should boot (blue LED). The OLED should light up (if firmware already flashed). The 12V rail should read 12.0V +/- 0.5V. The 5V rail should read 5.0V +/- 0.1V.

#### Step 8.2: TMC2209 Driver Boards

**Parts:** 4x TMC2209 boards (E2), perfboard (E14), JST-XH connectors

1. Set the UART addresses on each board using the MS1/MS2 solder jumpers:
   - Feeder motor driver: Address 0 (MS1 = low, MS2 = low)
   - Selector X driver: Address 1 (MS1 = high, MS2 = low)
   - Recombine X driver: Address 2 (MS1 = low, MS2 = high)
   - Recombine Z driver: Address 3 (MS1 = high, MS2 = high)
2. Mount all 4 drivers on the perfboard or directly on the electronics bay standoffs.
3. Wire the UART bus: all 4 drivers share a single UART TX/RX pair on ESP32 GPIO 12 (TX) and GPIO 13 (RX). Use 1K ohm resistors in series on each driver's UART pin if the driver board does not have them onboard. This is a daisy-chain bus.
4. Wire motor outputs: each TMC2209 has 4 motor output pins (A1, A2, B1, B2). Wire to the corresponding NEMA17 stepper coils using JST-XH connectors for each motor. Double-check coil pairing with a multimeter (continuity between A1-A2 and between B1-B2).
5. Wire motor power: connect 12V and GND to each driver's VM and GND pins.
6. Wire logic power: connect 5V to each driver's VCC pin.

**Critical warning:** Never connect or disconnect motor wires while the driver is powered. Disconnecting a motor under power will destroy the TMC2209 driver. Always power down first.

#### Step 8.3: ESP32 Wiring

**Parts:** ESP32 DevKit (E1), wire, JST-XH connectors

Wire the ESP32 GPIO pins to all peripherals. Suggested pin assignments (from BOM):

| Function | GPIO | Notes |
|---|---|---|
| TMC2209 UART TX | 12 | Shared bus to all 4 drivers |
| TMC2209 UART RX | 13 | Shared bus |
| Feeder STEP | 16 | Step pulse output |
| Feeder DIR | 17 | Direction output |
| Selector X STEP | 18 | Step pulse output |
| Selector X DIR | 19 | Direction output |
| Recombine X STEP | 25 | Step pulse output |
| Recombine X DIR | 26 | Direction output |
| Recombine Z STEP | 27 | Step pulse output |
| Recombine Z DIR | 14 | Direction output |
| OLED SDA | 21 | I2C data |
| OLED SCL | 5 | I2C clock (note: GPIO 5 has pull-up at boot) |
| Sensor: Feed exit | 34 | Input only, no pull-up (use external if needed) |
| Sensor: Post-singulation | 35 | Input only |
| Sensor: Selector throat | 36 | Input only |
| Sensor: Bin entry | 39 | Input only |
| Sensor: Recombine pickup | 23 | General GPIO |
| Sensor: Output checkpoint | 22 | General GPIO |
| Shuffle button | 15 | Internal pull-up, active-low |
| Stop/Clear Jam button | 0 | Internal pull-up, active-low (boot pin -- hold low at reset enters bootloader) |
| Solenoid (squaring tap) | 4 | Digital output, through MOSFET |

1. Wire all STEP and DIR pins to the corresponding TMC2209 inputs.
2. Wire I2C bus (SDA/SCL) to the OLED display.
3. Wire each TCRT5000 sensor module's digital output to the assigned GPIO pin. Connect sensor VCC and GND.
4. Wire the two panel buttons to their GPIO pins. Each button connects the pin to GND when pressed (using the ESP32's internal pull-up resistors).
5. If using a solenoid for the squaring station, wire GPIO 4 through a logic-level MOSFET (IRLZ44N or similar) to control the solenoid coil. Include a flyback diode across the solenoid.

#### Step 8.4: Sensor Installation

**Parts:** 6x TCRT5000 modules (E8), 6x sensor mount clips (P19), M3x6 bolts

Mount sensors at these positions along the card path:

1. **Feed exit sensor** -- at the feeder exit throat, detects a card leaving the feeder.
2. **Post-singulation sensor** -- just after the nip zone, confirms only one card passed.
3. **Selector throat sensor** -- at the entry to the selector card guide, confirms the card entered the selector.
4. **Bin entry sensor** -- at the bottom of the selector guide, confirms the card dropped into a bin.
5. **Recombine pickup sensor** -- on the pusher plate or above it, detects stack presence during extraction.
6. **Output checkpoint sensor** -- at the output tray entry, confirms final deck delivery.

For each sensor:
1. Snap or bolt the TCRT5000 module into a sensor mount clip (P19).
2. Bolt the clip to the appropriate location on the feeder, selector, or chassis.
3. Aim the sensor so the IR beam crosses the card path at 2-5 mm range.
4. Route the sensor wire through cable channels and secure with cable clips (P21).

#### Step 8.5: OLED Display and Buttons

**Parts:** SSD1306 OLED (E7), 2x panel buttons (X1), wire

1. Mount the OLED display in the electronics bay or on an enclosure panel. It connects via the I2C bus (4 wires: VCC, GND, SDA, SCL).
2. Mount the Shuffle and Stop buttons on an enclosure panel or a bracket on the chassis. Wire to their GPIO pins and GND.

#### Step 8.6: Cable Management

**Parts:** Cable clips (P21), zip ties (X4), cable sleeve (X3)

1. Route all motor cables through the chassis cable channels (8 mm wide grooves in the base plate top surface, running longitudinally and transversely).
2. Bundle motor cables using cable sleeve or spiral wrap.
3. Secure with printed cable clips at intervals.
4. Keep power wires (12V motor supply) separated from signal wires (sensor, UART) to reduce noise.
5. Leave enough slack at each motor and sensor for module removal during service.

---

### Phase 9: Firmware Flashing

#### Step 9.1: Flash ESP32

1. Connect the ESP32 to your computer via USB.
2. Open the firmware project in PlatformIO or Arduino IDE.
3. Verify the pin assignments in the firmware configuration file match the wiring from Step 8.3.
4. Compile and upload.
5. Open the serial monitor at 115200 baud. You should see boot messages.

#### Step 9.2: TMC2209 UART Verification

1. The firmware should attempt to communicate with each TMC2209 on the UART bus at startup.
2. Check the serial monitor for each driver responding at its address (0, 1, 2, 3). If a driver does not respond:
   - Verify MS1/MS2 jumper settings.
   - Check UART wiring (TX/RX not swapped).
   - Verify 5V power to the driver's VCC pin.
3. Once all 4 drivers respond, verify motor direction by commanding a small move on each axis. If a motor spins the wrong way, swap the DIR pin polarity in firmware (or swap one coil pair on the JST connector).

---

### Phase 10: First Power-On and Self-Test

**Do not load cards yet.** This phase verifies all axes move correctly and all sensors read properly.

#### Step 10.1: Boot Self-Test Sequence

Power on the machine with no cards loaded. The firmware should run an automatic self-test:

1. **OLED check:** Display shows "Shuffler V1 -- Self Test".
2. **Sensor check:** Each of the 6 TCRT5000 sensors is read. The display or serial monitor should report the analog value for each. With no cards present, all sensors should read "clear" (above the detection threshold).
3. **Motor check (feeder):** The feeder roller spins briefly in the forward direction, then stops. Listen for smooth microstepping -- no grinding or skipping.
4. **Motor check (selector X):** The selector carriage moves a short distance (10 mm) in each direction, then returns to start. Listen and watch for smooth motion.
5. **Motor check (recombine X):** Same as selector -- short jog in each direction.
6. **Motor check (recombine Z):** The pusher plate moves up 5 mm, then back down.
7. **Self-test result:** Display shows "PASS" or reports which subsystem failed.

If any motor stalls, grinds, or does not move:
- Check TMC2209 motor current setting (configured via UART -- start at 400 mA RMS and increase if needed).
- Check mechanical binding on that axis.
- Check wiring continuity on the motor connector.

If any sensor reads incorrectly:
- Verify the sensor is aimed at the card path.
- Check the sensor-to-surface distance (2-5 mm nominal for TCRT5000).
- Verify wiring to the correct GPIO pin.

#### Step 10.2: Homing Sequence

The selector and recombine X axes need a home position reference.

1. **Selector homing:** The selector carriage moves toward the -X end (motor mount end) until it triggers a homing sensor or endstop (microswitch or TCRT5000). The carriage should stop, back off 2 mm, then re-approach slowly for a precise home position. Record this as X = 0.
2. **Recombine X homing:** Same procedure for the recombine axis.
3. **Recombine Z homing:** The pusher plate moves down until it triggers a Z-home sensor or stalls against a physical stop (use StallGuard if TMC2209 StealthChop supports it, otherwise a microswitch).

Verify: command each axis to move to a known position and measure with calipers. The actual position should match the commanded position within 0.2 mm.

---

### Phase 11: Initial Calibration

#### Step 11.1: Selector Bin Positions

The selector needs to know the exact X position of each bin center. Because of print tolerances, these will differ slightly from the nominal 71.5 mm pitch.

1. Using the serial monitor or a calibration routine in firmware, manually jog the selector to center it over bin 0. Record the position.
2. Repeat for bins 1 through 7.
3. Store all 8 positions in firmware EEPROM/NVS.
4. Verify: command the selector to each bin position in sequence. At each position, drop a card through the guide by hand. The card should land cleanly in the target bin, not on a wall or in the adjacent bin.

#### Step 11.2: Recombine Bin Positions

Same procedure for the recombine X axis. The recombine must align its pusher plate with each bin's floor slot.

1. Jog the recombine X to each bin position.
2. At each position, command the Z axis to raise the pusher plate. Verify it enters the bin cavity cleanly without hitting bin walls.
3. Store all 8 positions in firmware EEPROM/NVS.

#### Step 11.3: Sensor Thresholds

Each TCRT5000 sensor needs a detection threshold calibrated to its specific mounting position and ambient light conditions.

1. With no card present, read the sensor's analog value. Record as the "clear" baseline.
2. Place a card at the sensor position. Read the analog value. Record as the "card present" value.
3. Set the threshold midway between clear and card-present values.
4. Store thresholds in firmware EEPROM/NVS.
5. Repeat for all 6 sensors.

#### Step 11.4: Feeder Speed and Current Tuning

1. Start with the feeder motor at 400 mA RMS and 60 mm/s feed speed.
2. Load 10 cards into the hopper.
3. Command the feeder to singulate one card. Observe:
   - Did exactly one card feed? (Check with the post-singulation sensor.)
   - Did it feed cleanly into the selector guide?
   - Any sounds of slipping, grinding, or multi-feeding?
4. Gradually increase speed toward the 120 mm/s target while monitoring for multi-feeds.
5. Adjust motor current (up to 600 mA rated) if the roller slips.
6. Adjust the retard pad spring preload (M3 set screw) if multi-feeds occur.

#### Step 11.5: Full Shuffle Dry Run

1. Load a full 52-card deck into the feeder hopper.
2. Command a single pass (pass 1): singulate all 52 cards into the 8 bins using a random bin assignment.
3. Observe the entire pass. Note any jams, mis-feeds, or mis-sorts.
4. Command the recombine sequence: collect all 8 bin stacks into the accumulator tray.
5. Run the squaring station.
6. Reload the squared deck into the feeder (pass 2).
7. Repeat singulation with a different random assignment.
8. Final recombine and deliver to the output tray.

**Target time:** 30 seconds for the full 2-pass shuffle (CYCLE_TIME_TARGET in constants.py). On initial runs, expect 45-60 seconds as you tune speeds.

---

### Phase 12: Final Checks

- [ ] All fasteners are tight, motor mount bolts have threadlocker.
- [ ] No loose wires; all connections use JST-XH or soldered joints with heat shrink.
- [ ] Belt tension is correct on both X axes (2-3 mm deflection).
- [ ] Feeder nip gap is set (0.30-0.40 mm).
- [ ] All 8 bin positions are calibrated and stored in firmware.
- [ ] All 6 sensors are calibrated with thresholds stored.
- [ ] Full 52-card shuffle completes without jams (run at least 5 consecutive shuffles).
- [ ] Output deck is fully shuffled (visually verify randomization).
- [ ] OLED displays status correctly during operation.
- [ ] Shuffle and Stop buttons function correctly.
- [ ] Machine sits level on rubber feet, does not walk during operation.
- [ ] Power supply is secure, IEC inlet fuse is correctly rated.

---

## Troubleshooting Quick Reference

| Symptom | Likely Cause | Fix |
|---|---|-----|
| Multi-feed (2+ cards at once) | Nip gap too wide or retard pad worn | Tighten set screw (reduce gap); replace retard pad material |
| No feed (roller slips) | Nip gap too tight, roller dirty, or motor current too low | Loosen set screw; clean roller with isopropanol; increase TMC2209 current |
| Card jams at feeder-selector handoff | Z step between feeder exit and selector entry | Add shim under selector rail; verify lead-in chamfer on selector guide |
| Card misses bin (lands on wall) | Selector position miscalibrated or belt skip | Recalibrate bin positions; check belt tension and pulley set screws |
| Card sticks in bin | Rough bin walls or bin too tight | Sand interior walls; verify bin internal width is 65.5 mm |
| Recombine pusher catches on bin wall | X position miscalibrated or pusher too wide | Recalibrate; verify pusher width is < bin internal width minus 1.0 mm |
| Stack wedges in squaring station | Stack too skewed or squaring pocket too tight | Run squaring tap multiple times; verify pocket width is 64.5 mm |
| Motor stalls (high-pitched whine) | Current too low or mechanical binding | Increase TMC2209 current (check motor rating); check for debris or misalignment |
| TMC2209 overheats | Current too high or poor ventilation | Reduce current; add heatsinks; ensure electronics bay has airflow |
| Sensor false triggers | Ambient light interference or wrong threshold | Shield sensors; recalibrate thresholds; use digital output mode with onboard potentiometer |
| ESP32 resets during motor moves | Power supply brownout | Verify 12V supply capacity; add capacitor (470 uF) across motor power bus |

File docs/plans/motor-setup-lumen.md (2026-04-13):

# Motor Setup — Lumen 3D Printer NEMA17 Salvage

Date: 2026-04-12

## Motor Identification

Lumen 3D printers use standard NEMA17 steppers, typically:

- **Frame:** 42×42×40 mm (standard body)
- **Step angle:** 1.8° (200 steps/rev)
- **Current rating:** ~1.5A (varies by Lumen model year)
- **Shaft:** 5 mm D-shaft, 24 mm length
- **Connector:** 4-pin JST-XH or bare leads (varies)

You have 4 motors. All 4 are the same model, which simplifies things.

### Axis Assignment

The BOM originally spec'd different motor sizes per axis. Your Lumen motors are all 40mm standard bodies, which is fine for every axis. The TMC2209 current limiting handles the rest.

| Axis | BOM Spec | Your Motor | Current Setting | Notes |
|---|---|---|---|---|
| Feeder (addr 0) | 25mm pancake, 600mA | Lumen 40mm, ~1.5A | **600 mA** | Overpowered but current-limited. Extra mass doesn't matter, feeder doesn't move fast. |
| Selector X (addr 1) | 40mm standard, 800mA | Lumen 40mm, ~1.5A | **800 mA** | Perfect match. |
| Recombine X (addr 2) | 40mm standard, 800mA | Lumen 40mm, ~1.5A | **800 mA** | Perfect match. |
| Recombine Z (addr 3) | 34mm short, 600mA | Lumen 40mm, ~1.5A | **600 mA** | Slightly larger than needed. More holding torque is actually good for Z. |

**No firmware changes needed.** The current limits in `config.h` are already set correctly. The TMC2209s will limit current regardless of the motor's rated current.

## Wiring the Motors

### Step 1: Identify Coils

Each NEMA17 has 4 wires = 2 coils. You need to identify which pairs are coil A and coil B.

**Method:** Touch two wires together and try to spin the shaft by hand. If the shaft resists (feels "sticky"), those two wires are one coil.

Typical Lumen motor wire colors:

| Wire | Coil | TMC2209 Pin |
|---|---|---|
| Black | A+ (1A) | OA1 |
| Green | A- (1B) | OA2 |
| Red | B+ (2A) | OB1 |
| Blue | B- (2B) | OB2 |

**If your colors differ:** use the touch-and-spin method. It doesn't matter which coil is A vs B... the motor just spins the other direction, and you can fix that in firmware by swapping `dir` polarity.

### Step 2: TMC2209 Address Configuration

The 4 TMC2209 boards share one UART bus. Each needs a unique address set via MS1/MS2 pins.

| Axis | UART Addr | MS1 | MS2 |
|---|---|---|---|
| Feeder | 0 | LOW (GND) | LOW (GND) |
| Selector X | 1 | HIGH (VCC) | LOW (GND) |
| Recombine X | 2 | LOW (GND) | HIGH (VCC) |
| Recombine Z | 3 | HIGH (VCC) | HIGH (VCC) |

**BIGTREETECH TMC2209 boards:** MS1 and MS2 are solder pads on the bottom. Default is both LOW (addr 0). Bridge the pads with solder to set HIGH.

**Fysetc TMC2209 boards:** Same concept, check the silkscreen for MS1/MS2 pad locations.

### Step 3: Wiring Diagram

For each motor axis:

```
ESP32                TMC2209              NEMA17
──────               ───────              ──────
STEP pin ──────────► STEP
DIR pin  ──────────► DIR
EN pin   ──────────► EN
                     OA1  ────────────► Black (A+)
                     OA2  ────────────► Green (A-)
                     OB1  ────────────► Red (B+)
                     OB2  ────────────► Blue (B-)
                     VM   ◄──── 12V PSU
                     GND  ◄──── 12V PSU GND
                     VIO  ◄──── 3.3V (from ESP32 3V3)
```

UART bus (all 4 drivers share):
```
ESP32 GPIO 13 (RX) ──────► TX (all 4 TMC2209 TX pins, direct connect)
ESP32 GPIO 12 (TX) ──────► RX (all 4 TMC2209 RX pins, via 1kΩ resistor)
```

**The 1kΩ resistor on TX is required.** TMC2209 UART is single-wire internally; the resistor prevents bus contention. Some breakout boards have this built in... check the schematic first.

### Step 4: Quick Smoke Test

Before installing in the machine, bench-test each motor individually:

1. Wire one motor + one TMC2209 to the ESP32
2. Set the TMC2209 to address 0 (MS1=LOW, MS2=LOW)
3. Flash the shuffler firmware
4. Open serial monitor at 115200 baud
5. Type `jog feed 200` — the motor should spin ~1 revolution and back
6. If it doesn't move: check UART connection, verify TMC version reads 0x21
7. Repeat for each motor, changing the UART address each time

### Lumen Motor Notes

- **Detent torque:** Lumen motors have noticeable detent torque (you can feel the steps when turning by hand with wires disconnected). This is normal for 1.8° motors.
- **Back-EMF:** If these motors were running at higher currents in the Lumen printer, the TMC2209 will run them much quieter at 600-800mA with StealthChop enabled.
- **Connector swap:** If the Lumen motors have JST-PH connectors (2.0mm pitch), you'll need to re-crimp to JST-XH (2.54mm pitch) or solder direct. Or just cut and solder.
- **Shaft length:** 24mm D-shaft should be fine for GT2 pulleys (need ~12mm engagement) and the feeder roller coupling.

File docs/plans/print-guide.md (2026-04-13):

# 3D Printing Guide -- Single-Deck Card Shuffler V1

Date: 2026-04-12
Reference CAD: `cad/constants.py`, module source files
Print tolerance defaults: 0.2 mm general, 0.1 mm tight (bearing bores, shaft fits)

---

## General Print Settings

Unless overridden per-part below, use these defaults:

| Setting | Value |
|---|---|
| Material | PETG (eSUN, Polymaker, or Hatchbox) |
| Nozzle | 0.4 mm |
| Layer height | 0.2 mm |
| Perimeters | 4 (gives ~1.6 mm wall, above the 1.2 mm minimum) |
| Top/bottom layers | 5 (1.0 mm solid) |
| Infill | 25% gyroid |
| Print speed | 50 mm/s for perimeters, 80 mm/s for infill |
| Bed temp | 80 C |
| Nozzle temp | 240 C (tune to your filament) |
| Elephant foot compensation | -0.15 mm first layer horizontal expansion |
| Seam position | Rear / nearest to edge (away from card-contact surfaces) |
| Support | Only where noted per part |

**TPU parts** use different settings -- see the TPU section at the end.

**Before printing any parts:** Print a tolerance test coupon with a 22.0 mm bore, a 5.0 mm bore, and a 3.2 mm bore. Measure with calipers. If your printer under/over-sizes bores by more than 0.1 mm, apply a horizontal expansion correction in your slicer globally rather than editing the CAD.

---

## Part-by-Part Guide

### P15: Chassis Base Frame (3 sections)

| | |
|---|---|
| **File** | `cad/chassis/chassis_section_0.step`, `chassis_section_1.step`, `chassis_section_2.step` |
| **Material** | PETG |
| **Quantity** | 3 sections |
| **Layer height** | 0.2 mm |
| **Infill** | 30% gyroid (structural -- carries all module loads) |
| **Estimated weight** | ~65 g per section (~200 g total) |
| **Estimated time** | ~4-5 hr per section |

**Why it is split:** The full chassis is ~785 mm long (total X extent). Each section is roughly 261 mm, which fits most 256 mm+ beds. The split points include alignment dowel pin holes (4.2 mm bores) and M3 bolt holes at each joint.

**Print orientation:** Print each section flat, base plate on the build plate. The side rail and end stop walls print vertically. This gives the best surface accuracy on the base plate top (Datum A) since it is the first layer's mating surface flipped over.

**Supports:** Not needed. The side rail, end stop, and stiffening rib all grow straight up from the base plate.

**Critical dimensions to check:**
- Base plate flatness: lay on a known-flat surface and check for rocking. Should be < 0.2 mm deviation across the section.
- Dowel pin bores at split joints: 4.2 mm diameter (4.0 mm pin + 0.2 mm clearance). Check with a 4.0 mm rod -- it should slide in with light finger pressure.
- M3 heat-set insert bores: 3.2 mm diameter, 5.0 mm deep. Check with a 3.0 mm drill bit -- slight resistance is correct.
- Side rail inner face: this is Datum B. It must be straight along its full length. Sight down the rail -- any bow > 0.3 mm will affect card alignment across the machine.

**Post-processing:**
1. Install M3 brass heat-set inserts with a soldering iron at 220 C. The chassis receives approximately 16 inserts for module mounting plus 4-6 for the electronics bay. Count from the CAD: 4 feeder mount, 12 bin bank mount, 6 selector mount, 3 recombine mount, 4 output mount, plus electronics bay inserts.
2. Ream the dowel pin bores with a 4.0 mm drill bit if the alignment pins do not slide in freely.
3. Lightly sand the base plate top surface (Datum A) with 220-grit on a flat surface to remove any first-layer texture. This is the reference for all module Z heights.
4. Test-fit the 3 sections together with dowel pins before installing any heat-set inserts. Confirm the side rail forms a continuous straight line across all joints.

---

### P1: Feeder Hopper + Base (Candidate A)

| | |
|---|---|
| **File** | `cad/feeder/feeder_candidate_a.step` |
| **Material** | PETG |
| **Quantity** | 1 |
| **Layer height** | 0.2 mm (0.12 mm for the exit throat zone -- see notes) |
| **Infill** | 25% gyroid |
| **Estimated weight** | ~120 g |
| **Estimated time** | ~6-8 hr |

**Print orientation:** Print with the NEMA17 mounting plate face down (motor side on the build plate). This puts the hopper opening at the top and the exit throat walls printing vertically. The critical throat gap dimension is formed by vertical walls, not horizontal bridges, which gives the best accuracy.

**Supports:** YES -- needed for:
- The bearing pockets in the side walls (horizontal cylindrical bores, 8.2 mm radius). Use tree supports or painted supports on these bores only. Breakaway style, not soluble, is fine since you will ream the bores.
- The roller pocket in the hopper floor (cylindrical bore through the floor).
- The exit guide channel ceiling (small horizontal overhang).
- The dovetail slide channel for the retard pad holder.

Keep supports away from the hopper interior walls -- these need a smooth finish for cards to slide.

**Layer height note:** If your slicer supports variable layer height (PrusaSlicer, OrcaSlicer), use 0.12 mm layers for the zone from Z = 0 to Z = 10 mm (the throat gap and roller pocket area). This improves the resolution of the 0.35 mm throat gap. The rest of the hopper can stay at 0.2 mm.

**Critical dimensions to check:**
- Exit throat gap: 0.8 mm nominal (CARD_THICKNESS 0.3 mm + 0.5 mm clearance). After printing, this will likely round to the nearest layer increment. Verify with feeler gauges -- a 0.3 mm gauge should pass, a 0.6 mm gauge should not pass easily. If the gap is too tight, sand lightly; if too loose, the retard pad spring preload compensates.
- Bearing bores in side walls: 8.2 mm radius (16.4 mm diameter). Test-fit a 625ZZ bearing (16 mm OD). It should press in with moderate force. If too tight, ream with a 16 mm drill bit or round file.
- NEMA17 pilot recess: 22.2 mm diameter, 2.5 mm deep. Test-fit against a NEMA17 face plate.
- NEMA17 mounting holes: 3.4 mm clearance for M3. Should accept M3 bolts freely.
- Shaft through-hole: 5.2 mm diameter. Must clear the 5 mm D-shaft with room to spin.
- Eccentric bushing bore (right side): 20.2 mm diameter. Verify the eccentric bushing fits.

**Post-processing:**
1. Carefully remove all supports from bearing pockets. Use a needle file to clean up the bore surface.
2. Ream both bearing bores for a smooth press-fit. Test-fit the 625ZZ bearings.
3. Clean out the roller pocket -- remove any stringing or support residue.
4. Sand the hopper interior walls lightly (320-grit) for smooth card feeding. Pay special attention to the exit throat channel walls.
5. Clean the retard pad dovetail channel so the holder slides freely.
6. Tap the M3 set screw hole in the rear wall (spring preload adjustment) with an M3 tap if needed, or install an M3 heat-set insert.
7. Install heat-set inserts for chassis mounting (4 locations on the base).

---

### P2: Feeder Roller (with O-ring grooves)

| | |
|---|---|
| **File** | (Generated from feeder CAD, or modeled separately) |
| **Material** | PETG |
| **Quantity** | 1 |
| **Layer height** | 0.12 mm (precision part) |
| **Infill** | 60% gyroid (structural rigidity) |
| **Estimated weight** | ~15 g |
| **Estimated time** | ~1.5 hr |

**Print orientation:** Print with the shaft bore vertical (bore axis = Z axis). This gives the best bore roundness. The O-ring grooves will be concentric rings formed by perimeters, which is ideal.

**Supports:** None needed.

**Critical dimensions to check:**
- Center bore: 5.2 mm for the D-shaft (5.0 mm shaft + 0.2 mm tight tolerance). The D-flat must be correct. Test-fit on the actual motor shaft.
- O-ring grooves: sized for 18-22 mm ID O-rings with 2-3 mm cross-section. Test-fit an O-ring -- it should seat fully in the groove without bulging above the roller OD.
- Roller OD: 20.0 mm. Measure with calipers.

**Post-processing:**
1. Ream the center bore with a 5 mm drill bit. The D-shaft must spin freely but without excessive wobble (< 0.1 mm radial play).
2. Test-fit O-rings. If grooves are too tight, widen gently with a hobby knife.

---

### P3: Retard Pad Holder

| | |
|---|---|
| **File** | (Derived from feeder CAD retard cavity dimensions) |
| **Material** | PETG |
| **Quantity** | 1 (print 2 -- this is a wear/tuning part) |
| **Layer height** | 0.2 mm |
| **Infill** | 40% gyroid |
| **Estimated weight** | ~8 g |
| **Estimated time** | ~0.5 hr |

**Print orientation:** Print flat, pad contact face up. The dovetail slide profile should be on the bottom layer for accuracy.

**Supports:** None.

**Critical dimensions:**
- Shoulder bolt pivot bore: 4.2 mm (4.0 mm shoulder + 0.2 mm clearance). Must spin freely on the shoulder bolt.
- Pad slot dimensions: 40 x 15 x 3 mm cavity for the cork/rubber retard pad material.
- Dovetail profile: must slide smoothly into the feeder housing channel.

**Post-processing:**
1. Ream pivot bore with a 4 mm drill bit.
2. Test-fit in the feeder dovetail channel. Sand the dovetail surfaces if the slide is too tight.
3. Cut the retard pad material (cork/rubber composite) to 40 x 15 mm and glue it into the slot with CA glue.

---

### P4: Selector Carriage + Card Guide

| | |
|---|---|
| **File** | `cad/selector/selector.step` (carriage portion) |
| **Material** | PETG |
| **Quantity** | 1 |
| **Layer height** | 0.2 mm |
| **Infill** | 30% gyroid |
| **Estimated weight** | ~45 g |
| **Estimated time** | ~3-4 hr |

**Print orientation:** Print with the carriage base plate on the build plate and the card guide channel growing upward. This puts the MGN12H mounting holes on the bottom face (best flatness) and the guide channel walls vertical (best dimensional accuracy for card slot width).

**Supports:** Minimal. The belt clamp overhang on the rear may need support depending on the angle. The card entry flare at the top of the guide is a small overhang that most printers handle without support (3 mm flare at roughly 45 degrees).

**Critical dimensions to check:**
- MGN12H bolt pattern: 20 mm x 12 mm spacing, M3 clearance holes (3.4 mm). Test-fit on the carriage block before full assembly.
- Card guide internal width: 65.5 mm (card width + 2 x 1.0 mm clearance). Measure at multiple heights along the channel.
- Card guide internal depth (slot thickness): 1.3 mm (card thickness + 1.0 mm clearance). Measure with feeler gauges.
- Belt slot: 7.0 mm wide x 2.0 mm tall. Test-fit a GT2 belt through the clamp.
- Guide channel height: 30 mm. Cards must slide through without catching.

**Post-processing:**
1. Sand the inside of the card guide channel walls (320-grit) for smooth card sliding.
2. Verify the belt clamp slot with a piece of GT2 belt. It should slide through with slight resistance when the clamp bolts are loose, and grip firmly when tightened.
3. No heat-set inserts needed -- this part uses through-bolts to the MGN12H block.

---

### P5: Selector Motor Mount Bracket

| | |
|---|---|
| **File** | `cad/selector/selector.step` (motor mount portion -- separate during export) |
| **Material** | PETG |
| **Quantity** | 1 |
| **Layer height** | 0.2 mm |
| **Infill** | 40% gyroid (carries motor cantilevered load) |
| **Estimated weight** | ~30 g |
| **Estimated time** | ~2 hr |

**Print orientation:** Print with the base flange on the build plate, motor mounting face vertical. The NEMA17 bolt pattern will be on a vertical face, which prints well with good hole accuracy.

**Supports:** Possibly needed under the base flange overhang where it meets the vertical plate, depending on the fillet radius. Use minimal breakaway supports.

**Critical dimensions to check:**
- NEMA17 mounting holes: 31 mm diagonal pattern, M3 clearance (3.4 mm).
- NEMA17 pilot recess: 22.2 mm diameter.
- Shaft through-hole: 5.2 mm diameter.
- Base flange mounting holes: M3 clearance (3.4 mm), positioned to reach chassis heat-set inserts.

**Post-processing:**
1. Install M3 heat-set inserts in the base flange if the chassis uses clearance holes at these positions (check CAD).
2. Test-fit a NEMA17 motor to the face plate. All 4 bolts should thread in without binding.

---

### P6: Selector Idler Bracket

| | |
|---|---|
| **File** | (Separate part, mirror of motor mount without the motor pattern) |
| **Material** | PETG |
| **Quantity** | 1 |
| **Layer height** | 0.2 mm |
| **Infill** | 30% gyroid |
| **Estimated weight** | ~20 g |
| **Estimated time** | ~1.5 hr |

**Print orientation:** Same as motor mount -- base flange down.

**Supports:** None typically needed.

**Critical dimensions:**
- Idler pulley bore: 5.2 mm for a 5 mm shoulder bolt or shaft.
- Base mounting holes: M3 clearance.

**Post-processing:**
1. Ream idler bore with a 5 mm drill bit.
2. Install heat-set inserts if applicable.

---

### P7: Bin Bank (8 bins, printed as sections)

| | |
|---|---|
| **File** | `cad/bin-bank/bin_bank.step` (full), split for printing |
| **Material** | PETG |
| **Quantity** | 4 sections (2-bin quarters) or 2 sections (4-bin halves) |
| **Layer height** | 0.2 mm (0.12 mm for the top 3 mm funnel zone if using variable layer height) |
| **Infill** | 20% gyroid (walls are the structural element, not infill) |
| **Estimated weight** | ~250 g total (~63 g per quarter, ~125 g per half) |
| **Estimated time** | ~5-6 hr per quarter, ~10-12 hr per half |

**Why it is split:** The full bin bank is 570 mm along X. This exceeds all common print beds. Split options:

- **4 quarters of 2 bins each (~143 mm):** Fits any printer with a 150 mm+ bed. Recommended for Bambu A1 Mini, Prusa MK3/MK4, Ender 3. Three alignment joints, each with 2 dowel pin holes and 2-3 bolt holes.
- **2 halves of 4 bins each (~285 mm):** Fits Bambu X1C (256 mm -- tight, may need diagonal), Prusa XL (360 mm), or any 300mm+ bed. One joint, fewer tolerance stack.

Choose based on your bed size. Halves are preferred if your bed allows it (fewer joints = better bin-to-bin accuracy).

**Splitting procedure:** In your slicer or CAD, cut the bin bank STL at the midpoint of the BIN_SPACING gap between bins 2-3, 4-5, and 6-7 (for quarters) or bins 4-5 (for halves). The 2.0 mm gap between bins provides a natural cut line. Add alignment dowel pin holes (4.0 mm, 8 mm deep) on each mating face during CAD export, or drill them after printing using a jig.

**Print orientation:** Print each section with the bin floor on the build plate and bin openings facing up. This gives:
- Best floor flatness (critical for recombine pusher plate interaction).
- Vertical bin walls (best dimensional accuracy for card clearance).
- Open top for easy support removal if any bridges require it.

**Supports:** Minimal. The funnel chamfers at the top of each bin are 3 mm at 45 degrees -- most printers handle 45-degree overhangs without support. If your printer struggles with 45-degree overhangs in PETG, add painted support on the funnel chamfer undersides only.

**Critical dimensions to check:**
- Bin internal width: 65.5 mm. Measure each bin with calipers at floor level and at the midpoint. All 8 bins should be within +/- 0.3 mm of each other.
- Bin internal depth: 90.9 mm. Same check.
- Bin pitch (center-to-center between adjacent bins): 71.5 mm nominal (69.5 mm cell + 2.0 mm spacing). Measure across multiple bins and compare to nominal. The selector will calibrate to actual positions, but they should be close.
- Floor flatness: lay a straightedge across each bin floor. Should be flat to 0.2 mm.
- Funnel chamfer: 3.0 mm at 45 degrees. Verify the top opening is wide enough for card entry. Test by dropping a card through each funnel -- it should fall freely without catching.

**Post-processing:**
1. Sand bin interior walls lightly (320-grit) to remove layer lines. Cards must slide freely without catching.
2. If printed as sections, join with 4.0 mm dowel pins and M3 bolts. Apply a thin bead of CA glue along the joint if desired for rigidity, but the bolts alone should suffice.
3. Install M3 heat-set inserts on the bottom face for chassis mounting (4 corner locations per the CAD).
4. Drop-test every bin with a playing card before assembly. The card should fall to the floor under gravity without sticking.

---

### P8: Recombine X Carriage + Pickup Head

| | |
|---|---|
| **File** | `cad/recombine/recombine.step` (carriage + pusher + elevator section) |
| **Material** | PETG |
| **Quantity** | 1 |
| **Layer height** | 0.2 mm |
| **Infill** | 30% gyroid |
| **Estimated weight** | ~50 g |
| **Estimated time** | ~4 hr |

**Print orientation:** Print with the MGN12H mounting face on the build plate. The elevator frame and pusher guide channel grow upward.

**Supports:** YES -- needed for:
- The pusher travel channel (internal horizontal ceiling).
- The vertical guide slots (if they have horizontal ceilings).
Use breakaway supports; avoid support touching the pusher travel bore surfaces.

**Critical dimensions to check:**
- MGN12H bolt pattern: 20 x 15 mm, M3 clearance.
- Pusher channel width: must accept the pusher plate (63.5 mm wide) with 0.4 mm total clearance.
- Elevator guide slot width: 8.0 mm, must accept the linear guide rods or printed slide.
- Sensor mount holes on pusher plate: M2 clearance (2.2 mm).

**Post-processing:**
1. Remove supports from the pusher channel. Clean the channel walls so the pusher plate slides freely.
2. Test-fit the pusher plate in the channel -- it should move smoothly through the full elevator travel without binding.
3. Install sensor onto the pusher plate boss.

---

### P9: Recombine Rail Mount Plate

| | |
|---|---|
| **File** | `cad/recombine/recombine.step` (rail plate section) |
| **Material** | PETG |
| **Quantity** | 2-3 sections (total plate is ~610 mm long) |
| **Layer height** | 0.2 mm |
| **Infill** | 30% gyroid |
| **Estimated weight** | ~60 g total |
| **Estimated time** | ~3-4 hr per section |

**Why it is split:** The rail mount plate is 610 mm x 43 mm x 4 mm. At 610 mm, it must be split into 2-3 sections similar to the chassis. Split at points between rail mounting holes (every 20 mm), adding dowel pin holes at each joint.

**Print orientation:** Print flat. The 4 mm plate thickness means this is essentially a thin slab. Print it with the rail-mounting face up (the top surface) so the MGN12 rail seats on the smoothest surface.

**Supports:** None.

**Critical dimensions:**
- Rail mounting holes: M3 clearance, spaced 20 mm along the length. These must be straight and consistent -- the linear rail must lay flat along the plate.
- Plate flatness: this is critical. After printing, lay the plate on a flat surface and check for warp. PETG plates this thin can warp. If warped, anneal in an oven at 80 C for 30 min, then cool slowly, or clamp flat while still warm off the print bed.
- M3 heat-set insert bores at corners for chassis mounting.

**Post-processing:**
1. Check flatness. If warped, re-flatten by warming and clamping.
2. Install heat-set inserts at the 4 corner chassis mounting points.
3. Bolt the MGN12H rail to the plate and verify the carriage slides smoothly across the full length without binding. If it binds, the plate is not flat enough.

---

### P10: Recombine Z Elevator Bracket

| | |
|---|---|
| **File** | `cad/recombine/recombine.step` (elevator frame section) |
| **Material** | PETG |
| **Quantity** | 1 |
| **Layer height** | 0.2 mm |
| **Infill** | 35% gyroid |
| **Estimated weight** | ~25 g |
| **Estimated time** | ~2 hr |

**Print orientation:** Print with the back face (motor mount side) on the build plate. The vertical guide channels grow upward.

**Supports:** May need support inside the travel channel ceiling. Use breakaway.

**Critical dimensions:**
- LM8UU bearing bores: should press-fit the 15 mm OD linear bearings. Print at 15.1 mm and ream if needed.
- Travel channel: must allow smooth vertical motion of the pusher carriage.

**Post-processing:**
1. Ream linear bearing bores. Press-fit LM8UU bearings.
2. Test vertical slide motion with the 8 mm rods installed.

---

### P11: Recombine Motor Mount Bracket (X axis)

| | |
|---|---|
| **File** | `cad/recombine/recombine.step` (motor mount section) |
| **Material** | PETG |
| **Quantity** | 1 |
| **Layer height** | 0.2 mm |
| **Infill** | 40% gyroid |
| **Estimated weight** | ~30 g |
| **Estimated time** | ~2 hr |

Same print approach as the selector motor mount (P5). Print with base flange down, motor face vertical. Check NEMA17 bolt pattern and pilot recess.

---

### P12: Recombine Z Motor Mount

| | |
|---|---|
| **File** | `cad/recombine/recombine.step` (Z motor bracket section) |
| **Material** | PETG |
| **Quantity** | 1 |
| **Layer height** | 0.2 mm |
| **Infill** | 30% gyroid |
| **Estimated weight** | ~20 g |
| **Estimated time** | ~1.5 hr |

**Print orientation:** Print flat, mounting face down.

**Critical dimensions:**
- 28BYJ-48 mounting tab holes: 35 mm spacing, 4.2 mm diameter (M4 clearance).
- Shaft bore: 28.2 mm diameter.

---

### P13: Output Tray

| | |
|---|---|
| **File** | `cad/output/output.step` |
| **Material** | PETG |
| **Quantity** | 1 |
| **Layer height** | 0.2 mm |
| **Infill** | 20% gyroid |
| **Estimated weight** | ~80 g |
| **Estimated time** | ~4 hr |

**Print orientation:** Print with the tray floor on the build plate, open top facing up. The side walls and rear wall grow vertically. The open front naturally faces one side.

**Supports:** None needed. The funnel chamfer at the top is a 3 mm overhang at 45 degrees, which prints fine. The spring pocket bores in the rear wall are horizontal cylinders -- if your printer handles small horizontal bores cleanly, no support needed. Otherwise, add painted support inside the spring bores only.

**Critical dimensions to check:**
- Pocket width: 66.5 mm (card width + 2 x 1.5 mm clearance). Generous.
- Pocket depth: 90.4 mm.
- Spring bore diameter: 6.0 mm, 12 mm deep. Test-fit the compression springs.
- M3 heat-set insert bores on the base: 3.2 mm, 4 positions.

**Post-processing:**
1. Sand interior pocket walls (320-grit) for smooth card handling.
2. Install 4 M3 heat-set inserts on the base.
3. Test-fit a deck of cards. The deck should drop in easily and sit square.

---

### P14: Electronics Bay / Tray

| | |
|---|---|
| **File** | (Designed to fit the chassis electronics bay recess) |
| **Material** | PETG |
| **Quantity** | 1 |
| **Layer height** | 0.2 mm |
| **Infill** | 20% gyroid |
| **Estimated weight** | ~40 g |
| **Estimated time** | ~2.5 hr |

**Print orientation:** Print flat, mounting face down.

**Supports:** None.

**Critical dimensions:**
- ESP32 standoff pattern: 44 x 22 mm hole spacing, M3.
- TMC2209 standoff pattern: 14 x 10 mm per board, 22 mm pitch between 4 boards.
- Ventilation slots: verify they are open (not bridged over).

**Post-processing:**
1. Install M3 heat-set inserts for each standoff position (4 for ESP32, 8 for TMC2209 boards, plus buck converter mounting).

---

### P16: Enclosure Panels (optional for V1)

| | |
|---|---|
| **Material** | PETG |
| **Quantity** | 4-6 panels |
| **Layer height** | 0.2 mm |
| **Infill** | 15% gyroid (cosmetic, not structural) |
| **Estimated weight** | ~180 g total |
| **Estimated time** | ~2-3 hr per panel |

These are optional for V1. Print them last, after the machine is working. Print flat, exterior face down for best surface finish.

---

### P19: Sensor Mount Clips

| | |
|---|---|
| **Material** | PETG |
| **Quantity** | 6 |
| **Layer height** | 0.2 mm |
| **Infill** | 30% gyroid |
| **Estimated weight** | ~2 g each |
| **Estimated time** | ~15 min each (batch all 6 on one plate, ~1 hr total) |

**Print orientation:** Print flat. These are small parts -- batch all 6 on one plate.

**Critical dimensions:**
- TCRT5000 module pocket: verify the sensor board snaps in or sits flat.
- M3 clearance hole for chassis/module mounting.

---

### P20: Belt Tensioner Blocks

| | |
|---|---|
| **Material** | PETG |
| **Quantity** | 2 |
| **Layer height** | 0.2 mm |
| **Infill** | 40% gyroid |
| **Estimated weight** | ~5 g each |
| **Estimated time** | ~20 min each |

Print flat. Check the spring bore and idler bolt hole dimensions.

---

### P21: Cable Clips / Guides

| | |
|---|---|
| **Material** | PETG |
| **Quantity** | 6 |
| **Layer height** | 0.2 mm |
| **Infill** | 20% gyroid |
| **Estimated weight** | ~1.3 g each |
| **Estimated time** | ~10 min each (batch all 6) |

Print flat. No critical dimensions. Snap-fit tabs should flex without cracking -- if they crack, your PETG is too brittle (try drying filament or raising nozzle temp).

---

## TPU Parts

Switch to these slicer settings for TPU 95A:

| Setting | Value |
|---|---|
| Material | TPU 95A (NinjaTek NinjaFlex, eSUN, or Sainsmart) |
| Nozzle temp | 225 C |
| Bed temp | 50 C |
| Print speed | 25 mm/s (all moves) |
| Retraction | Minimal (1-2 mm direct drive) or disabled (Bowden) |
| Infill | 100% (these are small, solid parts) |
| Layer height | 0.2 mm |

### P17: Feeder Roller Sleeve (TPU)

| | |
|---|---|
| **Material** | TPU 95A |
| **Quantity** | 1 (print 2 spares -- wear part) |
| **Estimated weight** | ~5 g |
| **Estimated time** | ~30 min |

**Print orientation:** Print standing upright (sleeve bore vertical). This gives the best bore roundness for press-fitting onto the PETG roller.

**Critical dimensions:**
- Inner bore: must press-fit over the PETG roller OD (20.0 mm). Print the bore at 19.6-19.8 mm so the TPU stretches onto the roller.
- Outer surface: this is the card-contact surface. It must be smooth and concentric.

**Post-processing:** None. The slight layer texture actually helps grip the card surface.

### P18: Output Tray Bumpers (TPU)

| | |
|---|---|
| **Material** | TPU 95A |
| **Quantity** | 2 |
| **Estimated weight** | ~1.5 g each |
| **Estimated time** | ~15 min each |

Print flat. These are simple pads that press-fit or glue into the output tray. No critical dimensions.

---

## Print Order Recommendation

Print in this order to allow early assembly and testing while later parts are still printing:

1. **Chassis sections** (P15) -- print all 3 first, they take the longest total time and everything mounts to them.
2. **Bin bank sections** (P7) -- second longest print. Start while you are post-processing the chassis.
3. **Feeder hopper** (P1) -- the most complex single print. Allocate time for support removal and bore reaming.
4. **Feeder roller** (P2) and **retard pad holder** (P3) -- quick prints, needed with the feeder.
5. **Selector carriage** (P4), **motor mount** (P5), **idler bracket** (P6) -- medium prints.
6. **Recombine parts** (P8-P12) -- multiple parts but none are very large.
7. **Output tray** (P13) -- straightforward print.
8. **Electronics bay** (P14), **sensor clips** (P19), **cable clips** (P21), **belt tensioners** (P20) -- small parts, batch-print.
9. **TPU parts** (P17, P18) -- print last since they require a filament change and slower speeds.
10. **Enclosure panels** (P16) -- optional, print after the machine is working.

---

## Total Print Estimates

| | |
|---|---|
| **Total PETG** | ~1,200 g (buy 2 kg to have margin for reprints) |
| **Total TPU** | ~8 g (you will need a full spool regardless) |
| **Total print time** | ~55-70 hours (varies by printer speed) |
| **Heat-set inserts consumed** | ~50 (buy 100 for margin) |

---

## Common Problems and Fixes

| Problem | Cause | Fix |
|---|---|-----|
| Bearing won't press into bore | Bore printed too small | Ream with correct-size drill bit. For 625ZZ, use 16 mm. |
| Heat-set insert goes in crooked | Bore printed with horizontal staircase | Print insert bores with bore axis vertical. If horizontal bore is unavoidable, oversize by 0.1 mm and use the soldering iron slowly. |
| Bin bank section warps after removal | PETG stress relief, thin floor | Let parts cool on the bed fully. If warped, anneal at 80 C or clamp flat. |
| Card catches on layer lines inside bin | Rough interior walls | Sand with 320-grit. For persistent issues, print outer walls only (no inner perimeter gap) or use "ironing" on top surfaces that cards contact. |
| Chassis sections don't align at joints | Dowel pin bores off-center | Ream bores slightly oversized (4.2 to 4.3 mm) and accept the minor play, or reprint. |
| Belt clamp doesn't grip GT2 belt | Slot too wide or smooth | Print a thin serrated insert for the clamp slot, or add a drop of CA glue to the belt-contact surface inside the clamp. |

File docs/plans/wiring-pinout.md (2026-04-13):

# Single-Deck Card Shuffler -- Wiring & Pinout Reference

Date: 2026-04-12
Controller: ESP32 DevKit V1 (WROOM-32, 38-pin)
Firmware: `firmware/shuffler/src/config.h`

This document contains everything needed to wire the shuffler from scratch
without reading the firmware source code.

---

## 1. Master Pinout Table

Every GPIO used on the ESP32, grouped by function.

| GPIO | Function | Signal Type | Direction | Pull | Wire Gauge | Notes |
|---|---|---|---|---|---|---|
| 0 | Stop / Clear-Jam button | Digital | Input | Internal pull-up | -- | BOOT button on DevKit. Active-low. |
| 2 | Recombine Z enable (EN) | Digital | Output | -- | 22 AWG | Active-low: LOW = enabled. Directly drives TMC2209 EN pin. |
| 4 | Recombine Z direction (DIR) | Digital | Output | -- | 22 AWG | |
| 5 | OLED I2C clock (SCL) | I2C | Bidirectional | 4.7k external pull-up to 3.3V | 26 AWG | Directly drives SSD1306 SCL. |
| 12 | TMC2209 UART TX | UART (Serial2 TX) | Output | -- | 22 AWG | Shared bus to all 4 TMC2209 drivers. |
| 13 | TMC2209 UART RX | UART (Serial2 RX) | Input | -- | 22 AWG | Shared bus from all 4 TMC2209 drivers. |
| 14 | Selector X enable (EN) | Digital | Output | -- | 22 AWG | Active-low. |
| 15 | Shuffle button | Digital | Input | Internal pull-up | -- | Active-low. Panel-mount momentary switch. |
| 16 | Recombine Z step (STEP) | Digital | Output | -- | 22 AWG | Pulse output. |
| 17 | Recombine X enable (EN) | Digital | Output | -- | 22 AWG | Active-low. |
| 18 | Recombine X direction (DIR) | Digital | Output | -- | 22 AWG | |
| 19 | Recombine X step (STEP) | Digital | Output | -- | 22 AWG | Pulse output. |
| 21 | OLED I2C data (SDA) | I2C | Bidirectional | 4.7k external pull-up to 3.3V | 26 AWG | Directly drives SSD1306 SDA. |
| 22 | Output tray sensor | Digital | Input (interrupt) | External 10k pull-up to 3.3V | 26 AWG | TCRT5000 digital out. Active-low. |
| 23 | Recombine pickup sensor | Digital | Input (interrupt) | External 10k pull-up to 3.3V | 26 AWG | TCRT5000 digital out. Active-low. |
| 25 | Feeder enable (EN) | Digital | Output | -- | 22 AWG | Active-low. |
| 26 | Feeder step (STEP) | Digital | Output | -- | 22 AWG | Pulse output, up to 4800 Hz. |
| 27 | Feeder direction (DIR) | Digital | Output | -- | 22 AWG | |
| 32 | Selector X direction (DIR) | Digital | Output | -- | 22 AWG | |
| 33 | Selector X step (STEP) | Digital | Output | -- | 22 AWG | Pulse output. |
| 34 | Feed exit sensor | Digital | Input (interrupt) | External 10k pull-up to 3.3V | 26 AWG | GPIO 34-39 are input-only, no internal pull-up. |
| 35 | Post-singulation sensor | Digital | Input (interrupt) | External 10k pull-up to 3.3V | 26 AWG | Input-only pin, no internal pull-up. |
| 36 (SVP) | Selector throat sensor | Digital | Input (interrupt) | External 10k pull-up to 3.3V | 26 AWG | Input-only pin, no internal pull-up. |
| 39 (SVN) | Bin entry sensor | Digital | Input (interrupt) | External 10k pull-up to 3.3V | 26 AWG | Input-only pin, no internal pull-up. |

**Important:** GPIO 34, 35, 36, 39 are input-only on the ESP32 and have no internal pull-up/pull-down. You must provide external 10k pull-up resistors to 3.3V for these four sensor pins.

---

## 2. TMC2209 UART Bus

All four TMC2209 stepper drivers share a single UART bus using different addresses.

| Parameter | Value |
|---|---|
| ESP32 serial port | Serial2 |
| TX pin | GPIO 12 |
| RX pin | GPIO 13 |
| Baud rate | 115200 |
| Sense resistor (R_sense) | 0.11 ohm |

### Driver Addressing

TMC2209 addresses are set via the MS1 and MS2 pins on each driver board:

| UART Addr | MS1 | MS2 | Motor | Current (mA RMS) |
|---|-----|-----|---|---|
| 0 | LOW | LOW | Feeder (singulation roller) | 600 |
| 1 | HIGH | LOW | Selector X (positions over 8 bins) | 800 |
| 2 | LOW | HIGH | Recombine X (traverses bins for pickup) | 800 |
| 3 | HIGH | HIGH | Recombine Z (elevator lift/lower) | 600 |

### UART Wiring Notes

- The TMC2209 UART is a single-wire half-duplex protocol. Some breakout boards
  (BIGTREETECH, Fysetc) have a 1k resistor between the TX and RX UART pads.
  If your board does not, place a **1k ohm resistor** in series on the TX line
  from the ESP32 to the shared bus.
- Daisy-chain topology: ESP32 TX (GPIO 12) connects to the UART/PDN pin on
  all four TMC2209 boards in parallel. RX (GPIO 13) connects to the same bus.
- Keep UART wires short (under 150 mm) and away from motor phase wires.
- Verify MS1/MS2 configuration matches the table above before powering on.
  Wrong addresses will cause UART communication failures during `motors_init()`.

---

## 3. Motor Wiring Table

Each motor has three control signals (STEP, DIR, EN) plus a 4-wire stepper coil connection.

### Control Signals

| Motor | STEP Pin | DIR Pin | EN Pin | TMC2209 Addr | Speed (steps/s) |
|---|---|---|---|---|---|
| Feeder | GPIO 26 | GPIO 27 | GPIO 25 | 0 | 4800 |
| Selector X | GPIO 33 | GPIO 32 | GPIO 14 | 1 | 4000 |
| Recombine X | GPIO 19 | GPIO 18 | GPIO 17 | 2 | 4000 |
| Recombine Z | GPIO 16 | GPIO 4 | GPIO 2 | 3 | 2000 |

**Enable logic:** All EN pins are active-low. LOW = motor energized. HIGH = motor free (no holding torque). The TMC2209 EN pin draws negligible current; direct ESP32 GPIO drive is fine.

### Motor Coil Connections (JST-XH 4-pin on driver side)

Standard NEMA 17 bipolar wiring. Verify coil pairs with a multimeter (each coil pair reads 2-10 ohms; no continuity between pairs).

| Driver Pin | Function | Recommended Wire Color | Motor Wire (typical) |
|---|---|---|---|
| A1 (OA1) | Coil A+ | Red | Red or Black |
| A2 (OA2) | Coil A- | Green | Green or Red |
| B1 (OB1) | Coil B+ | Blue | Blue or Yellow |
| B2 (OB2) | Coil B- | Yellow | Yellow or White |

**Warning:** Wire colors vary between motor manufacturers. Always identify coil pairs with a multimeter before connecting. Swapping wires within a pair (A1/A2 or B1/B2) reverses direction. Swapping wires between pairs (A and B) causes erratic behavior.

### Motor Specifications (from BOM)

| Motor | BOM # | Size | Holding Torque | Rated Current |
|---|---|---|---|---|
| Feeder | E3 | 42x42x25 mm (pancake) | >= 13 N-cm | 600 mA |
| Selector X | E4 | 42x42x40 mm (standard) | >= 40 N-cm | 800 mA |
| Recombine X | E5 | 42x42x40 mm (standard) | >= 40 N-cm | 800 mA |
| Recombine Z | E6 | 42x42x34 mm (short) | >= 26 N-cm | 600 mA |

---

## 4. Sensor Wiring Table

All six sensors are TCRT5000 IR reflective sensor modules. Signal is active-low: **LOW = beam broken (card detected)**, HIGH = clear.

| Sensor | Function | GPIO | Interrupt | Pull-Up | ISR Debounce |
|---|---|---|---|---|---|
| Feed exit | Card leaves feeder roller | 34 | Yes | External 10k to 3.3V (required) | 2000 us |
| Post-singulation | Confirms single card | 35 | Yes | External 10k to 3.3V (required) | 2000 us |
| Selector throat | Card enters selector | 36 | Yes | External 10k to 3.3V (required) | 2000 us |
| Bin entry | Card enters bin (shared beam) | 39 | Yes | External 10k to 3.3V (required) | 2000 us |
| Recombine pickup | Pickup head has card | 23 | Yes | External 10k to 3.3V (recommended) | 2000 us |
| Output tray | Card count checkpoint | 22 | Yes | External 10k to 3.3V (recommended) | 2000 us |

### Per-Sensor Wiring (3 wires each)

| TCRT5000 Module Pin | Connection | Notes |
|---|---|---|
| VCC | 3.3V rail | Do NOT use 5V -- the digital output of most TCRT5000 modules will exceed ESP32 3.3V input tolerance if powered from 5V. If your module requires 5V for the IR LED, add a voltage divider on the digital output pin. |
| GND | Common ground | Star ground to ESP32 GND. |
| DO (digital out) | ESP32 GPIO (see table) | Active-low. 10k pull-up to 3.3V on GPIOs 34/35/36/39 (no internal pull-up). GPIOs 22/23 can use internal pull-up but external is recommended for noise immunity. |

### Pull-Up Resistor Placement

- **GPIOs 34, 35, 36, 39:** External 10k pull-up to 3.3V is **mandatory** (these pins have no internal pull-up).
- **GPIOs 22, 23:** External 10k pull-up to 3.3V is **recommended** for consistency and noise rejection. Internal pull-up is available as a fallback.
- Place pull-up resistors on the sensor breakout perfboard, as close to the ESP32 as practical.

---

## 5. I2C Bus

| Parameter | Value |
|---|---|
| SDA | GPIO 21 |
| SCL | GPIO 5 |
| Bus speed | 400 kHz (Fast mode) |
| Pull-up resistors | 4.7k ohm to 3.3V on both SDA and SCL |

### Devices on Bus

| Device | Address | BOM # | Description |
|---|---|---|---|
| SSD1306 OLED | 0x3C | E7 | 0.96" 128x64 display for status and diagnostics |

### I2C Wiring Notes

- Many SSD1306 modules include on-board pull-ups (typically 10k). If your module
  has them, the additional 4.7k external pull-ups are still fine in parallel
  (effective ~3.2k, well within I2C spec).
- Keep I2C wires under 200 mm. Longer runs at 400 kHz may need lower pull-up
  values (2.2k) or reduced bus speed.
- Use twisted pair or keep SDA and SCL wires routed together.

---

## 6. Power Distribution

```
                        AC MAINS
                           |
                    [IEC C14 Inlet + Fused Switch] (BOM E11)
                    |  10A fuse, integrated switch
                           |
                    [12V 10A PSU] (BOM E9, Mean Well LRS-150-12)
                    |  120W capacity, ~60W steady-state draw
                           |
              +============ 12V BUS ============+
              |            |           |         |
          [TMC2209 #0] [TMC2209 #1] [TMC2209 #2] [TMC2209 #3]
          Feeder       Selector X   Recombine X  Recombine Z
          VM pin       VM pin       VM pin       VM pin
          600 mA       800 mA       800 mA       600 mA
              |
              |     +--- 12V IN
              |     |
              [5V 3A Buck Converter] (BOM E10, MP1584 or LM2596)
              |     |
              |     +--- 5V OUT
              |           |
              |     +-----+-------------------+
              |     |                         |
              [ESP32 VIN]              [OLED VCC (if 5V)]
              |  Peak ~500 mA         |  ~20 mA
              |                       |
              +--- 3.3V Rail (ESP32 internal regulator)
                    |           |           |
              [Sensor VCC x6]  [I2C Pull-ups]  [Button Pull-ups]
              ~10 mA each      to 3.3V         (internal)
              ~60 mA total
```

### Power Budget

| Load | Voltage | Current (max) | Notes |
|---|---|---|---|
| 4x TMC2209 motor drivers (VM) | 12V | 3.2A total | 800 mA per driver worst case |
| ESP32 DevKit | 5V via VIN | 500 mA peak | Wi-Fi transmit spikes |
| SSD1306 OLED | 3.3V or 5V | 20 mA | Check module; most accept either |
| 6x TCRT5000 sensors | 3.3V | 60 mA total | ~10 mA per module (IR LED + comparator) |
| **12V total** | | **~5A peak** | PSU provides 10A -- ample headroom |
| **5V total** | | **~600 mA peak** | Buck provides 3A -- ample headroom |

### Protection Recommendations

- **Input fuse:** 10A fast-blow in the IEC inlet (BOM E11 includes fuse holder).
- **12V bus:** Add a **5A automotive blade fuse** inline between the PSU and the
  TMC2209 VM distribution. Protects against motor driver shorts.
- **5V bus:** The buck converter module typically has built-in overcurrent
  protection. No additional fuse needed.
- **Reverse polarity:** Add a **Schottky diode** (1N5822 or similar, 3A rated)
  on the 12V input to the buck converter if there is any risk of reversed wiring.
  Better: use keyed connectors.
- **TMC2209 VM capacitor:** Place a **100 uF 25V electrolytic capacitor** across
  each TMC2209 VM/GND pair, close to the driver board. Most breakout boards
  include this; verify yours does.

---

## 7. Connector Reference

Standardize connectors for modular assembly and service.

| Connection | Connector Type | Pin Count | Notes |
|---|---|---|---|
| Motor coils (to TMC2209) | JST-XH 4-pin | 4 | A1, A2, B1, B2. Keyed to prevent reversal. |
| Motor control (STEP/DIR/EN) | JST-XH 3-pin | 3 | One per motor. ESP32 side: solder to perfboard header. |
| TMC2209 UART bus | JST-XH 2-pin | 2 | TX/RX daisy chain between driver boards. |
| Sensor (TCRT5000) | JST-XH 3-pin or Dupont 3-pin | 3 | VCC, GND, signal. Dupont acceptable for prototyping. |
| I2C OLED | JST-XH 4-pin or Dupont 4-pin | 4 | VCC, GND, SDA, SCL. |
| 12V PSU to distribution | XT60 or 5.5x2.1 mm barrel jack | 2 | XT60 for reliability, barrel jack for convenience. Solder direct for permanent install. |
| 12V to buck converter | JST-XH 2-pin or solder direct | 2 | Short run, solder preferred. |
| 5V buck to ESP32 | Dupont 2-pin or solder to VIN/GND | 2 | |
| Buttons (Shuffle, Stop) | JST-XH 2-pin | 2 | Signal + GND. Internal pull-up, so no VCC needed. |
| IEC mains inlet | C14 panel mount | 3 (L, N, PE) | BOM E11. Fused and switched. |

### Connector Crimping Notes

- Use proper JST-XH crimp terminals and a ratcheting crimp tool (Engineer PA-09
  or similar). Do not solder wires into JST housings -- the solder wicks up and
  causes brittle joints.
- Label all connectors with a label maker or heat-shrink labels. At minimum,
  label which motor/sensor each cable connects to.

---

## 8. Cable Routing Notes

### Chassis Cable Channels

The 3D-printed chassis base frame (BOM P15) and cable clips (BOM P21) provide
routing paths. Organize cables into three groups:

| Group | Cables | Routing Path |
|---|---|---|
| **Power (12V)** | PSU to TMC2209 VM bus, PSU to buck converter | Bottom of chassis, center channel. Use 18-20 AWG for 12V main run, 22 AWG for branches. |
| **Motor (STEP/DIR/EN + coil)** | 4x motor control bundles + 4x coil cables | Side channels, one bundle per motor. Keep left side for feeder + selector, right side for recombine X + Z. |
| **Signal (sensors + I2C + UART)** | 6x sensor cables, OLED I2C, TMC2209 UART | Top channel or opposite side from motor coil cables. |

### EMI / Noise Separation

- **Keep sensor signal wires at least 20 mm away from stepper motor coil cables.**
  Motor coil cables carry high-frequency chopped current (TMC2209 chopper at
  ~30 kHz) that can couple noise into sensor lines and cause false triggers.
- If sensor and motor cables must cross, cross them at **90 degrees** to minimize
  coupling.
- The TMC2209 UART wires are relatively robust but should still be routed away
  from motor coils. Keep UART cable length under 150 mm.
- Use **spiral wrap** (BOM X3) to bundle each motor's 7 wires (4 coil + 3 control)
  into a single harness.

### Bend Radius

- **Stepper motor cables (22 AWG stranded):** Minimum bend radius 10 mm (roughly
  5x wire diameter). Avoid sharp kinks at motor mount entry points.
- **Sensor cables (26 AWG stranded):** Minimum bend radius 6 mm.
- **GT2 belt:** Not a cable, but keep belt runs straight. Any twist or lateral
  bend degrades timing accuracy.

### Service Access

- Route all connectors to the **electronics bay** (BOM P14) so that any cable
  can be disconnected without disassembling mechanical components.
- Leave 30-50 mm of slack at each motor and sensor connector to allow module
  removal for service.
- The electronics bay should be accessible by removing a single enclosure panel
  (BOM P16) or from the bottom of the chassis.

---

## Quick Reference: Pin-to-Wire Color Scheme (Recommended)

A consistent color scheme makes debugging much faster.

| Function | Wire Color | Gauge |
|---|---|---|
| 12V power | Red | 20-22 AWG |
| 5V power | Orange | 22 AWG |
| 3.3V power | Yellow | 22-26 AWG |
| Ground | Black | Match power gauge |
| Motor STEP | White | 22 AWG |
| Motor DIR | Blue | 22 AWG |
| Motor EN | Green | 22 AWG |
| Motor coil A (A1, A2) | Red + Green (twisted pair) | 22 AWG |
| Motor coil B (B1, B2) | Blue + Yellow (twisted pair) | 22 AWG |
| Sensor signal | White | 26 AWG |
| I2C SDA | Purple | 26 AWG |
| I2C SCL | Gray | 26 AWG |
| UART TX | Orange | 22 AWG |
| UART RX | Brown | 22 AWG |
| Button signal | White or Green | 26 AWG |

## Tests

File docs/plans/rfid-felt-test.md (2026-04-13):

# RFID Through-Felt Validation Test

Date: 2026-04-12
Cost: ~$19
Time: ~30 minutes

## Purpose

Prove that a $4 RC522 module can read Faded Spade RFID poker cards through poker table felt before committing to the full ShuffleDeck RFID add-on ($300 BOM).

## Parts Needed

| Part | Cost | Source |
|---|---|---|
| RC522 RFID reader module (13.56MHz) | $4 | Amazon / AliExpress |
| Faded Spade RFID poker deck | $10-15 | fadedspade.com / Amazon |
| ESP32 DevKit (already have) | $0 | — |
| Jumper wires (already have) | $0 | — |
| Piece of poker table felt (~12"×12") | $0-5 | scrap from fabric store, or test on actual table |

Total: ~$19

## Wiring

RC522 → ESP32 (default VSPI):

| RC522 Pin | ESP32 Pin | Notes |
|---|---|---|
| SDA (SS) | GPIO 5 | Chip select |
| SCK | GPIO 18 | SPI clock |
| MOSI | GPIO 23 | SPI data out |
| MISO | GPIO 19 | SPI data in |
| RST | GPIO 22 | Reset |
| 3.3V | 3V3 | **Do NOT use 5V** |
| GND | GND | |

## Firmware

Flash the RFID reader firmware:

```bash
cd firmware/rfid-reader && pio run -t upload
```

Open serial monitor at 115200. The reader starts in read mode by default.

## Test Protocol

### Test 1: Bare Read (Baseline)

1. Place one Faded Spade card directly on the RC522 antenna
2. Serial monitor should print the card UID within 100ms
3. **Pass:** UID printed. **Fail:** no read, check wiring.

### Test 2: Single-Layer Felt

1. Place one layer of poker table felt over the RC522
2. Place card on top of felt
3. Record: does it read? What's the max distance (add cardboard spacers)?
4. **Expected:** reads through 1-3mm felt with no issues

### Test 3: Double-Layer Felt

1. Two layers of felt (simulates thick table padding)
2. Repeat read test
3. Record max read distance

### Test 4: Felt + Foam Padding

1. Felt + 3mm EVA foam (common table underlayment)
2. This is the realistic worst case for under-table mounting
3. **Target:** reliable reads at ≤ 5mm total material thickness

### Test 5: Multi-Card Stack

1. Stack of 2 cards through felt (hole card scenario: 2 cards dealt face down)
2. Can the reader identify both cards?
3. **Expected:** RC522 can read the bottom card but may miss the top due to collision. Anti-collision protocol should handle this, but test it.

### Test 6: Adjacent Card Interference

1. Place the reader under felt
2. Place target card directly above
3. Place two other cards 50mm to each side
4. Verify only the directly-above card is read
5. **This determines antenna spacing** for the 9-seat array

## Recording Results

For each test, record:

```
Test #: [1-6]
Material stack: [description]
Total thickness: [mm]
Read success: [yes/no]
Read time: [ms, from serial timestamp]
UID correct: [yes/no]
False reads from adjacent: [yes/no]
Max reliable distance: [mm]
```

## Decision Criteria

| Result | Decision |
|---|---|
| Reads through ≤ 3mm felt reliably | **GO** — proceed with RFID add-on development |
| Reads through ≤ 5mm with foam | **GO** — may need antenna tuning or PN532 upgrade |
| Fails through single felt layer | **STOP** — RC522 won't work, evaluate PN532 or custom antenna |
| Can't distinguish 2 stacked cards | **ACCEPTABLE** — design for bottom-card-only read, deal with it in software |
| Adjacent card crosstalk at 50mm | **CONCERN** — need smaller antenna or shielding between seats |

## If It Works

The full RFID add-on design:

- 9× RC522 modules (one per seat), ~$36
- Custom PCB or perfboard with SPI multiplexer (CD74HC4067), ~$5
- Under-felt antenna array with 3D-printed positioning jig
- ESP32 reader (can be same as shuffler or dedicated)
- Total RFID hardware: ~$50-80 (well under the $300 ceiling, which includes the streaming software and enclosure)

The `firmware/rfid-reader/` code already handles card database, WebSocket broadcast, and registration mode. The `site/overlay.html` streaming overlay is ready to receive card events.

## If It Doesn't Work

Alternatives in order of preference:

1. **PN532 module** ($8-12) — better antenna, NFC-A + NFC-B, longer range. Drop-in replacement for RC522 in the firmware (different library but same SPI bus).
2. **Custom antenna** — etch or wind a larger loop antenna tuned to 13.56MHz. More range but more complexity.
3. **Different card brand** — try RFIDup or TP-RFID cards, which may have stronger transponders than Faded Spade.
4. **Above-table reader** — redesign as a card slot reader instead of through-felt. Less elegant but guaranteed to work. This is what casino systems do.

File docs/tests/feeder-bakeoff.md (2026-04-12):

# Feeder Singulator Bakeoff Protocol

Purpose: settle premise P4 (feeder separator mechanism) before committing to feeder CAD. This is a Tier 1 bench test per the test plan. Built in isolation, no integration.

Gate: cannot begin feeder CAD until one candidate has a declared winner across the full deck envelope matrix.

## Candidates

Four candidates, ordered by implementation cost:

| # | Name | Mechanism | Why include |
|---|---|---|---|
| A | **Friction roller + retard pad** | Driven O-ring roller opposes a high-friction stationary pad. Top card has roller grip, second card is pinned by pad. | Current plan baseline. Proven in every desktop laser printer and scanner on the planet. |
| B | **Escapement gate** | A reciprocating finger below the stack presents one card at a time into a pickup path. Mechanical singulation by geometry, not friction. | Deterministic — no slip variance. But parts count is higher. |
| C | **Vacuum pickup** | Small diaphragm pump pulls card to a suction head, which swings or translates to a transport belt. | Immune to card thickness variance. Used in check scanners. |
| D | **Kicker + weight** | Spring-loaded weight pushes stack against a rotating kicker wheel. Kicker strikes only the bottom card laterally. | Used in casino-grade Shuffle Master machines. Mechanically simple but requires good side-rails. |

Slot-feed / belt-drag variants excluded — too exotic for V1.

## Deck envelope (V1 locked: 2 conditions)

Per Targets section in the plan, V1 ships against **new KEM + new Bee only**. Worn/humid/warped are V2 scope.

| Code | Deck | Condition |
|---|---|---|
| KN | New KEM (100% plastic, ~0.31 mm) | Fresh from pack |
| BN | New Bee (paper/cellulose, ~0.29 mm) | Fresh from pack |

Total: 2 decks × 52 cards = 104 cards per test cycle. Informational-only runs on worn/humid/warped decks are encouraged if time permits — the data feeds V2, and a candidate that silently fails worn decks may need an asterisk in the V1 decision.

**Worst case for Phase 2 DOE:** BN (new Bee paper). Paper cards pick up roller static faster than plastic, have more surface friction variance, and are more sensitive to nip force. If a candidate passes BN at the 120 mm/s target feed speed (pro-am cycle = 30 s), the architecture is sound.

## Metrics

All measured per test cycle:

| Metric | How | Target |
|---|---|---|
| **Double-feed rate** | Dual photo-break sensors 20 mm apart at feeder exit. If both block simultaneously for more than threshold, call a double. | ≤ 1 per 2000 singulations |
| **Miss rate** | Timeout: roller turns 2× card length with no sensor trigger. | ≤ 1 per 500 singulations |
| **Skew** | Feeler gauge or camera measurement of card exit angle. | ≤ 2° deviation from normal |
| **Transit time variance (σ)** | Logic analyzer captures edge timestamps. Measure σ of sensor1→sensor2 interval. | σ < 10% of mean for winner |
| **Jam events** | Count of stalls requiring manual assist. | 0 for winner |
| **Wear-part swap time** | Stopwatch replacing the friction/retard surface. | ≤ 60 s |

## Protocol

Run in this exact order. No re-ordering, no "just trying one config real quick" between candidates — that's how contamination happens.

### Phase 0 — Build the rig (once)

One shared frame accepts all four candidate heads via a bolt pattern with ±0.1 mm repeatability. The frame holds:

- Adjustable input hopper (angle 5°-25°, side rails ±2 mm)
- Exit throat with dual photo-break sensors (IR, Vishay TCRT5000 or equivalent)
- Logic analyzer breakout (Saleae or Pulseview on cheap clone)
- Load cell under the retard pad mount (or gram gauge for initial cal)
- ESP32 running a minimal count-and-log firmware
- Removable catch tray at exit

Document the rig with a dimensioned sketch before running any candidate. No "I'll remember" — rig drift is the single biggest source of bakeoff noise.

### Phase 1 — Per-candidate cold run (500 cards per deck condition)

For each candidate A-D, in order:

1. Install the candidate head on the frame. Record install time.
2. Set the candidate's nominal tuning per the table below.
3. Load deck KN. Run 500 singulations (≈ 10 deck cycles).
4. Log every event: pass / double / miss / skew / jam. Dump to CSV.
5. Reload with BN. Repeat.
6. Total per candidate Phase 1: 500 × 2 = 1000 cards.
7. **No tuning changes within Phase 1.** Tune-then-test is later.

Nominal starting tuning:

| Candidate | Nominal |
|---|---|
| A (friction+retard) | 225 gf nip, 60A durometer O-ring, cast silicone retard pad, 80 mm/s feed |
| B (escapement) | 100 ms dwell per cycle, 2 mm throw, spring return |
| C (vacuum) | 15 kPa vacuum, 50 ms dwell, transport belt at 100 mm/s |
| D (kicker+weight) | 300 gf weight, kicker at 60 RPM, side-rail gap 0.5 mm above thickest deck |

### Phase 2 — Survivor tuning DOE (winners from Phase 1 only)

Any candidate with >5% error rate in Phase 1 is eliminated. For the remaining candidates:

Factorial DOE with 3 factors × 3 levels (27 runs per survivor). Factors differ by candidate:

**Candidate A:** nip force (150/225/300 gf), roller durometer (50A/60A/70A), feed speed (40/80/120 mm/s)
**Candidate B:** dwell (50/100/200 ms), throw (1.5/2.0/2.5 mm), spring preload (low/mid/high)
**Candidate C:** vacuum (10/15/20 kPa), dwell (25/50/100 ms), belt speed (50/100/150 mm/s)
**Candidate D:** weight (200/300/400 gf), kicker RPM (40/60/80), side-gap (0.3/0.5/0.8 mm above stack)

Each run: 500 cards on worst-case deck (BN — new Bee paper, the hardest in V1 envelope) at **120 mm/s feed speed** (the 30 s cycle time target). Log the same metrics as Phase 1.

Pick the minimum-variance config per candidate (not lowest-mean — variance dominates long-tail jams).

### Phase 3 — Wear life (winner only)

Run 5000 cards continuous on the tuned winner. Log error rate every 500 cards. Pass criterion: error rate at 5000 marker ≤ 2× error rate at 500 marker.

Replace wear part. Re-run 500 cards. Pass criterion: error rate returns to ≤ 1.2× baseline.

### Phase 4 — Wear-part swap time

Stopwatch the swap. ≤ 60 s. No re-calibration afterward should be required to pass a 500-card validation run.

## Decision rule

Winner is the candidate that:

1. Passes all Phase 1 deck envelope conditions (≤ 1 double/2000, ≤ 1 miss/500)
2. Has the lowest combined (doubles + misses + jams) in Phase 2 at its tuned config
3. Survives Phase 3 wear test within spec
4. Meets Phase 4 swap time

Tiebreakers in order: parts count, BOM cost, tuning sensitivity (measured by DOE response surface steepness — flatter is better).

If all four fail Phase 1: the design premise is wrong. Stop and escalate — do not proceed to CAD.

## Data format

Per-cycle CSV at `docs/tests/feeder-bakeoff/<candidate>-<deck>-<timestamp>.csv`:

```
event_id,t_ms,sensor1_edge,sensor2_edge,classification,transit_ms,notes
1,1023,1020,1089,single,69,
2,2155,2150,2225,single,75,
3,3201,3198,3198,double,0,simultaneous_block
```

Aggregate per candidate at `docs/tests/feeder-bakeoff/<candidate>-summary.md`.

## What we're NOT testing here

- Full machine timing interactions — that's Tier 2
- Recombine → pass 2 handoff squareness — that's a different bench rig
- Bin entry jams — that's the selector rig
- Firmware jam recovery — that's Tier 2 with the full state machine

Keep this rig isolated. Single purpose: which singulator survives 6 deck conditions with the best margin.

## Estimated effort

- Phase 0 (rig build): 1-2 days
- Phase 1 (4 candidates × 3000 cards): 1 day if singulation is at ~80 mm/s
- Phase 2 (DOE on survivors): 1-2 days
- Phase 3 (wear life): half day
- Phase 4 (swap time): 30 minutes

Budget: one focused week, including data analysis.

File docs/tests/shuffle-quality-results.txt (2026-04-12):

Running 10000 trials per architecture (seed=42, N=52 cards)
Uniform expectation: rising ~26.5, adjacency ~0.98, displacement ~17.3, Kendall τ ~663

Architecture                            Rising seq.     Adjacency     Displace.      Kendall τ   ≈ Riffles
---------------------------------------------------------------------------------------------------------
True uniform (ideal)                   26.48 ± 2.10   0.98 ± 0.99  17.32 ± 1.53     663 ±   63       10.00
Riffle shuffle × 1                      2.00 ± 0.00  24.98 ± 3.57  13.02 ± 2.09     339 ±   54        1.00
Riffle shuffle × 2                      4.00 ± 0.00  12.22 ± 3.04  15.20 ± 1.74     503 ±   62        2.00
Riffle shuffle × 3                      7.98 ± 0.14   6.00 ± 2.26  16.31 ± 1.63     585 ±   63        3.00
Riffle shuffle × 4                     14.47 ± 1.03   3.07 ± 1.71  16.84 ± 1.56     626 ±   63        4.00
Riffle shuffle × 5                     20.09 ± 1.78   1.88 ± 1.37  17.07 ± 1.55     644 ±   63        5.00
Riffle shuffle × 6                     23.32 ± 2.03   1.36 ± 1.18  17.23 ± 1.55     655 ±   64        6.00
Riffle shuffle × 7                     24.96 ± 2.06   1.15 ± 1.08  17.25 ± 1.53     658 ±   63        7.00
Riffle shuffle × 8                     25.74 ± 2.09   1.08 ± 1.04  17.30 ± 1.54     661 ±   64        8.00
Riffle shuffle × 10                    26.32 ± 2.12   1.00 ± 0.99  17.32 ± 1.54     662 ±   63       10.00
Current plan: 2-pass 8-bin FIFO        26.08 ± 2.11   1.45 ± 1.21  17.16 ± 1.54     651 ±   63        9.20
Current plan: 2-pass 8-bin LIFO        26.11 ± 2.08   1.43 ± 1.19  17.21 ± 1.54     654 ±   63        9.27
Alt: 2-pass 16-bin FIFO                26.37 ± 2.12   1.11 ± 1.06  17.28 ± 1.53     659 ±   63       10.00
Alt: 1-pass 16-bin FIFO                24.88 ± 2.09   3.35 ± 1.80  16.78 ± 1.58     622 ±   63        6.95
Alt: 1-pass 24-bin FIFO                25.46 ± 2.11   2.41 ± 1.52  16.99 ± 1.56     637 ±   63        7.64
Alt: 1-pass 32-bin FIFO                25.68 ± 2.10   2.01 ± 1.40  17.06 ± 1.56     643 ±   63        7.93
Alt: 3-pass 8-bin FIFO                 26.46 ± 2.10   1.03 ± 1.01  17.31 ± 1.53     662 ±   63       10.00
Alt: 3-pass 8-bin LIFO                 26.56 ± 2.10   0.93 ± 0.97  17.35 ± 1.53     664 ±   63       10.00
Alt: Slot-rack 52 (1 pass)             26.48 ± 2.11   0.98 ± 0.99  17.32 ± 1.53     663 ±   63       10.00

=========================================================================================================
VERDICT
=========================================================================================================
  Current plan: 2-pass 8-bin FIFO       rising=26.08  ~9.20 riffles  PASS
  Current plan: 2-pass 8-bin LIFO       rising=26.11  ~9.27 riffles  PASS
  Alt: 2-pass 16-bin FIFO               rising=26.37  ~10.00 riffles  PASS
  Alt: 1-pass 16-bin FIFO               rising=24.88  ~6.95 riffles  FAIL
  Alt: 1-pass 24-bin FIFO               rising=25.46  ~7.64 riffles  FAIL
  Alt: 1-pass 32-bin FIFO               rising=25.68  ~7.93 riffles  FAIL
  Alt: 3-pass 8-bin FIFO                rising=26.46  ~10.00 riffles  PASS
  Alt: 3-pass 8-bin LIFO                rising=26.56  ~10.00 riffles  PASS
  Alt: Slot-rack 52 (1 pass)            rising=26.48  ~10.00 riffles  PASS

Pass criterion: rising-sequence mean >= 26.0 (target: ~7 riffle equivalent).
Uniform reference: 26.48.

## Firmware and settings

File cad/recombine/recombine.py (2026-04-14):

# Recombine module — pusher/elevator mechanism for collecting partial stacks
# from the 8-bin bank and assembling them into a single deck.
# Requires: pip install build123d
#
# After pass 1, cards are distributed across 8 bins. The recombine module
# traverses the bin bank along the X axis, lifts each partial stack with a
# pusher plate rising through the bin floor, captures it onto a collection
# tray, and accumulates all stacks into a single deck. The combined deck
# then routes back to the feeder (pass 2) or to the output tray (final).
#
# Mechanism:
#   - Linear rail (MGN12H) for X travel along bin bank
#   - Vertical elevator (small stepper/servo) lifts pusher plate through bin floor
#   - Collection tray with side guides holds the growing stack
#   - NEMA17 drives the X axis via belt or leadscrew
#
# Run standalone:  python recombine.py
# Outputs:         recombine.step

from __future__ import annotations

import sys
from pathlib import Path

# Allow importing shared constants when run standalone
sys.path.insert(0, str(Path(__file__).resolve().parent.parent))

from build123d import (
    BuildPart,
    Box,
    Cylinder,
    Location,
    Align,
    Axis,
    Mode,
    Plane,
    export_step,
    Pos,
    Rot,
    chamfer,
    fillet,
)
import build123d as bd

from constants import (
    CARD_WIDTH,
    CARD_HEIGHT,
    CARD_THICKNESS,
    DECK_COUNT,
    DECK_STACK_HEIGHT_MAX,
    BIN_COUNT,
    BIN_INTERNAL_WIDTH,
    BIN_INTERNAL_DEPTH,
    BIN_INTERNAL_HEIGHT,
    BIN_WALL_THICKNESS,
    BIN_FLOOR_THICKNESS,
    BIN_SPACING,
    NEMA17_FACE,
    NEMA17_HOLE_SPACING,
    NEMA17_HOLE_DIAMETER,
    NEMA17_PILOT_DIAMETER,
    NEMA17_PILOT_DEPTH,
    NEMA17_SHAFT_DIAMETER,
    PRINT_TOL_DEFAULT,
    PRINT_TOL_TIGHT,
    M3_CLEARANCE_HOLE,
    M3_HEATSET_BORE,
    M3_HEATSET_LENGTH,
    CARD_CLEARANCE_WIDTH,
    CARD_CLEARANCE_HEIGHT,
)

# ── Recombine parameters ──────────────────────────────────────────────
# Pusher plate
PUSHER_CLEARANCE = 0.5           # mm per side — plate must fit inside bin cavity
PUSHER_PLATE_THICKNESS = 2.0     # mm
PUSHER_PLATE_WIDTH = CARD_WIDTH + 2 * CARD_CLEARANCE_WIDTH - 2 * PUSHER_CLEARANCE
PUSHER_PLATE_DEPTH = CARD_HEIGHT + 2 * CARD_CLEARANCE_HEIGHT - 2 * PUSHER_CLEARANCE

# Sensor-guided pusher — Finding 1 from datum/tolerance budget
# Contact/proximity sensor mount on pusher plate (microswitch or IR reflective)
SENSOR_BOSS_WIDTH = 10.0         # mm — mounting boss on pusher plate
SENSOR_BOSS_DEPTH = 8.0          # mm
SENSOR_BOSS_HEIGHT = 5.0         # mm — raised boss for microswitch lever
SENSOR_MOUNT_HOLE_DIA = 2.2      # mm — M2 clearance for sensor screws
SENSOR_MOUNT_HOLE_SPACING = 6.0  # mm — distance between sensor mounting holes

# Compliant pusher surface — spring-loaded flex zone
# A thin flex zone around the plate perimeter conforms to single-card stacks
FLEX_ZONE_WIDTH = 3.0            # mm — width of the thinned perimeter ring
FLEX_ZONE_THICKNESS = 0.6        # mm — thin enough to flex under light load
FLEX_ZONE_STEP = PUSHER_PLATE_THICKNESS - FLEX_ZONE_THICKNESS  # step depth

# Elevator — full range: 0 to bin height (accommodates 1-10 card stacks)
ELEVATOR_TRAVEL = BIN_INTERNAL_HEIGHT + 5.0   # mm — full bin height + clearance
ELEVATOR_FRAME_WALL = 3.0        # mm
ELEVATOR_FRAME_WIDTH = PUSHER_PLATE_WIDTH + 2 * ELEVATOR_FRAME_WALL
ELEVATOR_FRAME_DEPTH = 30.0      # mm — compact frame behind pusher
ELEVATOR_FRAME_HEIGHT = ELEVATOR_TRAVEL + 20.0  # mm — room for travel + mount

# Collection tray
TRAY_WALL = 2.5                  # mm
TRAY_GUIDE_HEIGHT = DECK_STACK_HEIGHT_MAX + 5.0  # mm — holds full deck + margin
TRAY_INT_WIDTH = CARD_WIDTH + 2 * CARD_CLEARANCE_WIDTH
TRAY_INT_DEPTH = CARD_HEIGHT + 2 * CARD_CLEARANCE_HEIGHT
TRAY_FLOOR_THICKNESS = 2.0      # mm
TRAY_FUNNEL_CHAMFER = 2.0       # mm — entry chamfer for card alignment

# Linear rail (MGN12H)
MGN12_RAIL_WIDTH = 12.0          # mm
MGN12_RAIL_HEIGHT = 8.0          # mm
MGN12_CARRIAGE_WIDTH = 27.0      # mm
MGN12_CARRIAGE_LENGTH = 34.7     # mm
MGN12_CARRIAGE_HEIGHT = 13.0     # mm
MGN12_MOUNT_HOLE_SPACING_X = 20.0  # mm
MGN12_MOUNT_HOLE_SPACING_Y = 15.0  # mm

# X-axis travel — must span all bin positions
BIN_CELL_WIDTH = BIN_INTERNAL_WIDTH + 2 * BIN_WALL_THICKNESS
BANK_TOTAL_WIDTH = BIN_COUNT * BIN_CELL_WIDTH + (BIN_COUNT - 1) * BIN_SPACING

# Motor mount plate
MOTOR_PLATE_THICKNESS = 5.0      # mm
MOTOR_PLATE_WIDTH = NEMA17_FACE + 10.0
MOTOR_PLATE_HEIGHT = NEMA17_FACE + 10.0

# Z-axis small stepper mount (NEMA14 or micro servo — using 28BYJ-48 envelope)
Z_MOTOR_FACE = 28.0             # mm (28BYJ-48 diameter approximation)
Z_MOTOR_MOUNT_WIDTH = 35.0      # mm
Z_MOTOR_MOUNT_HEIGHT = 20.0     # mm
Z_MOTOR_MOUNT_THICKNESS = 3.0   # mm
Z_MOTOR_HOLE_SPACING = 35.0     # mm (28BYJ-48 mounting tab spacing)
Z_MOTOR_HOLE_DIA = 4.2          # mm (M4 clearance for 28BYJ mounting)

# Rail mount plate
RAIL_MOUNT_PLATE_THICKNESS = 4.0  # mm
RAIL_MOUNT_PLATE_WIDTH = BANK_TOTAL_WIDTH + 40.0  # mm — extends past bank ends
RAIL_MOUNT_PLATE_HEIGHT = MGN12_CARRIAGE_WIDTH + 16.0  # mm

# Chassis mounting
CHASSIS_MOUNT_INSET = 10.0       # mm from plate edges

# ── Squaring station — Finding 2 from datum/tolerance budget ─────────
# Jogger/tap squaring step between accumulator tray and feeder reload.
# Tight pocket with funnel entry narrows stack skew from +/-1.5mm to ~0.
SQUARING_CLEARANCE = 0.5         # mm per side — tight guides (vs 2.0mm in hopper)
SQUARING_INT_WIDTH = CARD_WIDTH + 2 * SQUARING_CLEARANCE   # ~64.5 mm
SQUARING_INT_DEPTH = CARD_HEIGHT + 2 * SQUARING_CLEARANCE  # ~89.9 mm
SQUARING_WALL = 3.0              # mm — thick enough to mount solenoid
SQUARING_FLOOR = 2.0             # mm
SQUARING_HEIGHT = DECK_STACK_HEIGHT_MAX + 5.0  # mm — full deck + margin
SQUARING_FUNNEL_LENGTH = 20.0    # mm — entry funnel narrows over this distance
SQUARING_FUNNEL_EXTRA_WIDTH = 3.0  # mm per side — wider at entry, narrows to tight
SQUARING_FUNNEL_EXTRA_DEPTH = 3.0  # mm per side

# Solenoid tap arm mount on squaring station side wall
SOLENOID_MOUNT_WIDTH = 15.0      # mm — mounting plate for small solenoid
SOLENOID_MOUNT_HEIGHT = 12.0     # mm
SOLENOID_MOUNT_THICKNESS = 3.0   # mm — boss thickness on exterior wall
SOLENOID_HOLE_DIA = 3.4          # mm — M3 clearance
SOLENOID_HOLE_SPACING = 10.0     # mm — between mounting holes
SOLENOID_SLOT_WIDTH = 8.0        # mm — slot through wall for tap arm lever
SOLENOID_SLOT_HEIGHT = 6.0       # mm

# Squaring station offset from accumulator tray
SQUARING_X_OFFSET = 0.0          # mm — centered on same axis as tray
SQUARING_Y_OFFSET = (TRAY_INT_DEPTH / 2 +
                     TRAY_WALL +
                     10.0)        # mm — positioned after tray, toward feeder


def build_recombine() -> bd.Part:
    """Build the recombine module assembly as a single part."""

    with BuildPart() as recombine:

        # ── 1. Pusher plate with sensor mount and compliant surface ────
        # Flat plate that rises through the bin floor slot to lift cards.
        # Includes a contact-sensor boss and a compliant flex-zone perimeter
        # so the pusher can detect and conform to single-card stacks (0.3 mm).
        with BuildPart() as _pusher:
            Box(PUSHER_PLATE_WIDTH, PUSHER_PLATE_DEPTH, PUSHER_PLATE_THICKNESS,
                align=(Align.CENTER, Align.CENTER, Align.MIN))

            # 1a. Compliant flex zone — thin perimeter ring that flexes under
            # light load, allowing the pusher to pick up even a single card
            # without missing it.  We subtract a perimeter step leaving only
            # FLEX_ZONE_THICKNESS at the outer rim.
            inner_w = PUSHER_PLATE_WIDTH - 2 * FLEX_ZONE_WIDTH
            inner_d = PUSHER_PLATE_DEPTH - 2 * FLEX_ZONE_WIDTH
            with BuildPart(mode=Mode.SUBTRACT):
                with bd.Locations([(0, 0, PUSHER_PLATE_THICKNESS)]):
                    Box(
                        PUSHER_PLATE_WIDTH,
                        PUSHER_PLATE_DEPTH,
                        FLEX_ZONE_STEP,
                        align=(Align.CENTER, Align.CENTER, Align.MAX),
                    )
            # Re-add the rigid center island
            with BuildPart():
                with bd.Locations([(0, 0, PUSHER_PLATE_THICKNESS)]):
                    Box(
                        inner_w,
                        inner_d,
                        FLEX_ZONE_STEP,
                        align=(Align.CENTER, Align.CENTER, Align.MAX),
                    )

            # 1b. Sensor mounting boss — small raised boss on the underside
            # of the pusher plate for a microswitch lever or IR reflective
            # sensor facing downward to detect stack contact.
            with BuildPart():
                with bd.Locations([(0, 0, 0)]):
                    Box(
                        SENSOR_BOSS_WIDTH,
                        SENSOR_BOSS_DEPTH,
                        SENSOR_BOSS_HEIGHT,
                        align=(Align.CENTER, Align.CENTER, Align.MAX),
                    )

            # Sensor mounting holes (2x M2 through the boss)
            for dx in (-SENSOR_MOUNT_HOLE_SPACING / 2,
                        SENSOR_MOUNT_HOLE_SPACING / 2):
                with BuildPart(mode=Mode.SUBTRACT):
                    with bd.Locations([(dx, 0, -SENSOR_BOSS_HEIGHT - 1.0)]):
                        Cylinder(
                            radius=SENSOR_MOUNT_HOLE_DIA / 2,
                            height=SENSOR_BOSS_HEIGHT + 2.0,
                            align=(Align.CENTER, Align.CENTER, Align.MIN),
                        )

        # ── 2. Collection / accumulator tray ───────────────────────────
        # Positioned above the pusher mechanism, offset in Z.
        tray_z_offset = ELEVATOR_FRAME_HEIGHT + 5.0

        # Outer shell
        tray_ext_w = TRAY_INT_WIDTH + 2 * TRAY_WALL
        tray_ext_d = TRAY_INT_DEPTH + 2 * TRAY_WALL
        tray_ext_h = TRAY_GUIDE_HEIGHT + TRAY_FLOOR_THICKNESS

        with BuildPart():
            with bd.Locations([(0, 0, tray_z_offset)]):
                Box(
                    tray_ext_w,
                    tray_ext_d,
                    tray_ext_h,
                    align=(Align.CENTER, Align.CENTER, Align.MIN),
                )

        # Hollow interior
        with BuildPart(mode=Mode.SUBTRACT):
            with bd.Locations([(0, 0, tray_z_offset + TRAY_FLOOR_THICKNESS)]):
                Box(
                    TRAY_INT_WIDTH,
                    TRAY_INT_DEPTH,
                    TRAY_GUIDE_HEIGHT,
                    align=(Align.CENTER, Align.CENTER, Align.MIN),
                )

        # Funnel chamfer — wider opening at the top for card alignment
        funnel_w = TRAY_INT_WIDTH + 2 * TRAY_FUNNEL_CHAMFER
        funnel_d = TRAY_INT_DEPTH + 2 * TRAY_FUNNEL_CHAMFER
        funnel_h = TRAY_FUNNEL_CHAMFER
        with BuildPart(mode=Mode.SUBTRACT):
            with bd.Locations([(0, 0, tray_z_offset + tray_ext_h)]):
                Box(
                    funnel_w,
                    funnel_d,
                    funnel_h,
                    align=(Align.CENTER, Align.CENTER, Align.MAX),
                )

        # Floor slot — through-hole for pusher plate to rise into tray
        with BuildPart(mode=Mode.SUBTRACT):
            with bd.Locations([(0, 0, tray_z_offset - 1.0)]):
                Box(
                    PUSHER_PLATE_WIDTH + 2 * PRINT_TOL_DEFAULT,
                    PUSHER_PLATE_DEPTH + 2 * PRINT_TOL_DEFAULT,
                    TRAY_FLOOR_THICKNESS + 2.0,
                    align=(Align.CENTER, Align.CENTER, Align.MIN),
                )

        # ── 3. Elevator frame ─────────────────────────────────────────
        # Vertical frame that guides the pusher plate up and down.
        # Positioned below the tray.
        elev_z = 0.0

        # Main frame body (C-channel shape around the pusher travel)
        with BuildPart():
            with bd.Locations([(0, -TRAY_INT_DEPTH / 2, elev_z)]):
                Box(
                    ELEVATOR_FRAME_WIDTH,
                    ELEVATOR_FRAME_DEPTH,
                    ELEVATOR_FRAME_HEIGHT,
                    align=(Align.CENTER, Align.MAX, Align.MIN),
                )

        # Hollow out the travel channel for the pusher plate
        channel_w = PUSHER_PLATE_WIDTH + 2 * PRINT_TOL_DEFAULT
        channel_d = ELEVATOR_FRAME_DEPTH - ELEVATOR_FRAME_WALL
        channel_h = ELEVATOR_TRAVEL + 2.0
        with BuildPart(mode=Mode.SUBTRACT):
            with bd.Locations([(0, -TRAY_INT_DEPTH / 2 + ELEVATOR_FRAME_WALL, elev_z + ELEVATOR_FRAME_WALL)]):
                Box(
                    channel_w,
                    channel_d,
                    channel_h,
                    align=(Align.CENTER, Align.MAX, Align.MIN),
                )

        # Vertical guide slots (two slots for linear rod or rail guidance)
        guide_slot_width = 8.0
        guide_slot_depth = ELEVATOR_FRAME_DEPTH + 2.0
        for x_sign in (-1, 1):
            gx = x_sign * (PUSHER_PLATE_WIDTH / 2 + ELEVATOR_FRAME_WALL / 2)
            with BuildPart(mode=Mode.SUBTRACT):
                with bd.Locations([(gx, -TRAY_INT_DEPTH / 2 + 1.0, elev_z + ELEVATOR_FRAME_WALL)]):
                    Box(
                        guide_slot_width,
                        guide_slot_depth,
                        ELEVATOR_TRAVEL,
                        align=(Align.CENTER, Align.MAX, Align.MIN),
                    )

        # ── 4. Z-axis motor mount (28BYJ-48 or micro servo) ──────────
        z_motor_z = elev_z + ELEVATOR_FRAME_HEIGHT / 2
        z_motor_y = -TRAY_INT_DEPTH / 2 - ELEVATOR_FRAME_DEPTH

        # Mount bracket
        with BuildPart():
            with bd.Locations([(0, z_motor_y, z_motor_z)]):
                Box(
                    Z_MOTOR_MOUNT_WIDTH,
                    Z_MOTOR_MOUNT_THICKNESS,
                    Z_MOTOR_MOUNT_HEIGHT,
                    align=(Align.CENTER, Align.MAX, Align.CENTER),
                )

        # Motor shaft through-hole
        with BuildPart(mode=Mode.SUBTRACT):
            with bd.Locations([(0, z_motor_y + 1.0, z_motor_z)]):
                Cylinder(
                    radius=Z_MOTOR_FACE / 2 + PRINT_TOL_DEFAULT,
                    height=Z_MOTOR_MOUNT_THICKNESS + 2.0,
                    align=(Align.CENTER, Align.CENTER, Align.MIN),
                    rotation=(90, 0, 0),
                )

        # Motor mounting holes (2x for 28BYJ-48 tab pattern)
        for dx in (-Z_MOTOR_HOLE_SPACING / 2, Z_MOTOR_HOLE_SPACING / 2):
            with BuildPart(mode=Mode.SUBTRACT):
                with bd.Locations([(dx, z_motor_y + 1.0, z_motor_z)]):
                    Cylinder(
                        radius=Z_MOTOR_HOLE_DIA / 2,
                        height=Z_MOTOR_MOUNT_THICKNESS + 2.0,
                        align=(Align.CENTER, Align.CENTER, Align.MIN),
                        rotation=(90, 0, 0),
                    )

        # ── 5. Linear rail mount plate (MGN12H, X axis) ──────────────
        # Horizontal plate that the rail screws onto, spans the bin bank.
        rail_plate_z = -RAIL_MOUNT_PLATE_THICKNESS

        with BuildPart():
            with bd.Locations([(0, 0, rail_plate_z)]):
                Box(
                    RAIL_MOUNT_PLATE_WIDTH,
                    RAIL_MOUNT_PLATE_HEIGHT,
                    RAIL_MOUNT_PLATE_THICKNESS,
                    align=(Align.CENTER, Align.CENTER, Align.MIN),
                )

        # Rail mounting holes — M3, spaced every 20 mm along rail length
        import math
        rail_hole_count = int(RAIL_MOUNT_PLATE_WIDTH / 20.0)
        rail_start_x = -(rail_hole_count - 1) * 20.0 / 2
        for i in range(rail_hole_count):
            hx = rail_start_x + i * 20.0
            with BuildPart(mode=Mode.SUBTRACT):
                with bd.Locations([(hx, 0, rail_plate_z - 1.0)]):
                    Cylinder(
                        radius=M3_CLEARANCE_HOLE / 2,
                        height=RAIL_MOUNT_PLATE_THICKNESS + 2.0,
                        align=(Align.CENTER, Align.CENTER, Align.MIN),
                    )

        # Chassis mounting holes — M3 heat-set inserts at plate corners
        for cx in (-RAIL_MOUNT_PLATE_WIDTH / 2 + CHASSIS_MOUNT_INSET,
                    RAIL_MOUNT_PLATE_WIDTH / 2 - CHASSIS_MOUNT_INSET):
            for cy in (-RAIL_MOUNT_PLATE_HEIGHT / 2 + CHASSIS_MOUNT_INSET,
                        RAIL_MOUNT_PLATE_HEIGHT / 2 - CHASSIS_MOUNT_INSET):
                with BuildPart(mode=Mode.SUBTRACT):
                    with bd.Locations([(cx, cy, rail_plate_z - 0.5)]):
                        Cylinder(
                            radius=M3_HEATSET_BORE / 2,
                            height=M3_HEATSET_LENGTH + 1.0,
                            align=(Align.CENTER, Align.CENTER, Align.MIN),
                        )

        # ── 6. NEMA17 mount for X-axis drive ──────────────────────────
        # Motor bracket at one end of the rail plate.
        motor_x = RAIL_MOUNT_PLATE_WIDTH / 2 + MOTOR_PLATE_THICKNESS / 2
        motor_z = rail_plate_z + RAIL_MOUNT_PLATE_THICKNESS / 2

        with BuildPart():
            with bd.Locations([(motor_x, 0, motor_z + MOTOR_PLATE_WIDTH / 2)]):
                Box(
                    MOTOR_PLATE_THICKNESS,
                    MOTOR_PLATE_HEIGHT,
                    MOTOR_PLATE_WIDTH,
                    align=(Align.CENTER, Align.CENTER, Align.CENTER),
                )

        # NEMA17 mounting holes (4x M3 on 31 mm diagonal pattern)
        half_spacing = NEMA17_HOLE_SPACING / 2
        for dz in (-half_spacing, half_spacing):
            for dy in (-half_spacing, half_spacing):
                with BuildPart(mode=Mode.SUBTRACT):
                    with bd.Locations([(motor_x - MOTOR_PLATE_THICKNESS / 2 - 1.0, dy, motor_z + MOTOR_PLATE_WIDTH / 2 + dz)]):
                        Cylinder(
                            radius=M3_CLEARANCE_HOLE / 2,
                            height=MOTOR_PLATE_THICKNESS + 2.0,
                            align=(Align.CENTER, Align.CENTER, Align.MIN),
                            rotation=(0, 90, 0),
                        )

        # Central pilot hole for NEMA17
        with BuildPart(mode=Mode.SUBTRACT):
            with bd.Locations([(motor_x - MOTOR_PLATE_THICKNESS / 2 - 1.0, 0, motor_z + MOTOR_PLATE_WIDTH / 2)]):
                Cylinder(
                    radius=(NEMA17_PILOT_DIAMETER / 2) + PRINT_TOL_TIGHT,
                    height=MOTOR_PLATE_THICKNESS + 2.0,
                    align=(Align.CENTER, Align.CENTER, Align.MIN),
                    rotation=(0, 90, 0),
                )

        # Shaft through-hole
        with BuildPart(mode=Mode.SUBTRACT):
            with bd.Locations([(motor_x - MOTOR_PLATE_THICKNESS / 2 - 2.0, 0, motor_z + MOTOR_PLATE_WIDTH / 2)]):
                Cylinder(
                    radius=(NEMA17_SHAFT_DIAMETER / 2) + PRINT_TOL_TIGHT,
                    height=MOTOR_PLATE_THICKNESS + 4.0,
                    align=(Align.CENTER, Align.CENTER, Align.MIN),
                    rotation=(0, 90, 0),
                )

        # ── 7. Squaring station ───────────────────────────────────────
        # Finding 2: stack skew +/-1.5mm eats all clearance in the 2.0mm
        # hopper.  This pocket has tight side guides (~0.5mm clearance/side)
        # with a funnel entry that narrows over 20mm.  A solenoid tap arm
        # pushes the stack against the opposite wall to square it before
        # the stack is transferred into the feeder hopper for pass 2.

        sq_x = SQUARING_X_OFFSET
        sq_y = SQUARING_Y_OFFSET
        sq_z = tray_z_offset   # same height datum as accumulator tray

        sq_ext_w = SQUARING_INT_WIDTH + 2 * SQUARING_WALL
        sq_ext_d = SQUARING_INT_DEPTH + 2 * SQUARING_WALL
        sq_ext_h = SQUARING_HEIGHT + SQUARING_FLOOR

        # 7a. Main pocket body
        with BuildPart():
            with bd.Locations([(sq_x, sq_y, sq_z)]):
                Box(
                    sq_ext_w,
                    sq_ext_d,
                    sq_ext_h,
                    align=(Align.CENTER, Align.CENTER, Align.MIN),
                )

        # Hollow interior — tight pocket
        with BuildPart(mode=Mode.SUBTRACT):
            with bd.Locations([(sq_x, sq_y, sq_z + SQUARING_FLOOR)]):
                Box(
                    SQUARING_INT_WIDTH,
                    SQUARING_INT_DEPTH,
                    SQUARING_HEIGHT,
                    align=(Align.CENTER, Align.CENTER, Align.MIN),
                )

        # 7b. Funnel entry — wider opening at top that narrows to tight
        # guides over SQUARING_FUNNEL_LENGTH.  Modeled as a subtracted
        # tapered box (approximated by a wider cut at the top).
        funnel_top_w = SQUARING_INT_WIDTH + 2 * SQUARING_FUNNEL_EXTRA_WIDTH
        funnel_top_d = SQUARING_INT_DEPTH + 2 * SQUARING_FUNNEL_EXTRA_DEPTH
        funnel_h = SQUARING_FUNNEL_LENGTH

        # Upper wide portion of funnel (subtract at the top of the pocket)
        with BuildPart(mode=Mode.SUBTRACT):
            with bd.Locations([(sq_x, sq_y, sq_z + sq_ext_h)]):
                Box(
                    funnel_top_w,
                    funnel_top_d,
                    funnel_h,
                    align=(Align.CENTER, Align.CENTER, Align.MAX),
                )

        # 7c. Solenoid tap arm mount — boss on the +X exterior wall with
        # mounting holes and a slot for the tap lever to pass through.
        sol_x = sq_x + sq_ext_w / 2 + SOLENOID_MOUNT_THICKNESS / 2
        sol_y = sq_y
        sol_z = sq_z + SQUARING_FLOOR + SQUARING_HEIGHT / 2

        # Mounting boss on exterior wall
        with BuildPart():
            with bd.Locations([(sol_x, sol_y, sol_z)]):
                Box(
                    SOLENOID_MOUNT_THICKNESS,
                    SOLENOID_MOUNT_WIDTH,
                    SOLENOID_MOUNT_HEIGHT,
                    align=(Align.CENTER, Align.CENTER, Align.CENTER),
                )
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

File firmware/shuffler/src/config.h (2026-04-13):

#pragma once

// ============================================================
// Single-Deck Shuffler — Pin Definitions & Constants
// ESP32 DevKit V1
// ============================================================

// ------------------------------------------------------------
// Stepper motor pins — 4 axes, each with STEP + DIR + ENABLE
// TMC2209 UART shares a single hardware serial bus (Serial2)
// Each driver has a unique UART address (0-3)
// ------------------------------------------------------------

// Feeder motor (singulation roller drive)
#define PIN_FEED_STEP         26
#define PIN_FEED_DIR          27
#define PIN_FEED_EN           25
#define FEED_TMC_ADDR         0

// Selector X-axis (positions over 8 bins)
#define PIN_SEL_STEP          33
#define PIN_SEL_DIR           32
#define PIN_SEL_EN            14
#define SEL_TMC_ADDR          1

// Recombine X-axis (traverses bins for pickup)
#define PIN_REC_X_STEP        19
#define PIN_REC_X_DIR         18
#define PIN_REC_X_EN          17
#define REC_X_TMC_ADDR        2

// Recombine Z-axis elevator (lifts/lowers pickup head)
#define PIN_REC_Z_STEP        16
#define PIN_REC_Z_DIR         4
#define PIN_REC_Z_EN          2
#define REC_Z_TMC_ADDR        3

// TMC2209 shared UART bus (Serial2)
#define PIN_TMC_RX            13
#define PIN_TMC_TX            12
#define TMC_UART_BAUD         115200
#define TMC_R_SENSE           0.11f   // current sense resistor (ohms)

// ------------------------------------------------------------
// Sensor pins — IR break-beam, active-low (LOW = beam broken)
// All pins must support GPIO interrupts
// ------------------------------------------------------------

#define PIN_SENS_FEED_EXIT    34    // feeder exit (card leaves roller)
#define PIN_SENS_POST_SING    35    // post-singulation confirmation
#define PIN_SENS_SEL_THROAT   36    // selector throat transit
#define PIN_SENS_BIN_ENTRY    39    // bin entry confirmation (shared beam)
#define PIN_SENS_REC_PICKUP   23    // recombine pickup confirmation
#define PIN_SENS_OUTPUT       22    // output tray count checkpoint

// Sensor count for iteration
#define NUM_SENSORS           6

// Sensor index constants (for arrays)
#define SENS_IDX_FEED_EXIT    0
#define SENS_IDX_POST_SING    1
#define SENS_IDX_SEL_THROAT   2
#define SENS_IDX_BIN_ENTRY    3
#define SENS_IDX_REC_PICKUP   4
#define SENS_IDX_OUTPUT       5

// ------------------------------------------------------------
// UI pins
// ------------------------------------------------------------

#define PIN_BTN_SHUFFLE       15    // shuffle button, active-low, internal pull-up
#define PIN_BTN_STOP          0     // stop / clear-jam button (BOOT button)
#define PIN_BUZZER            -1    // piezo buzzer disabled (no free GPIO)
// To add buzzer: free a pin by removing one motor axis enable or use I2C GPIO expander

// OLED I2C (SSD1306 128x64)
#define PIN_OLED_SDA          21
#define PIN_OLED_SCL          5     // I2C clock for OLED

#define OLED_ADDR             0x3C
#define OLED_WIDTH            128
#define OLED_HEIGHT           64

// ------------------------------------------------------------
// Mechanical constants
// ------------------------------------------------------------

#define NUM_BINS              8       // storage bins for randomization
#define DECK_SIZE             52      // standard poker deck
#define NUM_PASSES            2       // two-pass shuffle

// Feeder geometry
#define FEED_SPEED_MMS        120.0   // target feed speed (mm/s)
#define CARD_LENGTH_MM        63.0    // poker card short dimension (feed direction)
#define CARD_WIDTH_MM         89.0    // poker card long dimension
#define SENSOR_SPACING_MM     20.0    // feed_exit to post_singulation distance

// Stepper mechanical parameters
#define FEED_STEPS_PER_MM     40.0    // feeder: steps per mm of card travel
#define SEL_STEPS_PER_BIN     200     // selector: steps between adjacent bins
#define REC_X_STEPS_PER_BIN   200     // recombine X: steps between adjacent bins
#define REC_Z_STEPS_DOWN      800     // recombine Z: steps from top to pickup
#define REC_Z_STEPS_UP        800     // recombine Z: steps from pickup to clear

// Motor speeds (steps/sec)
#define FEED_SPEED_SPS        ((uint32_t)(FEED_SPEED_MMS * FEED_STEPS_PER_MM))
#define SEL_SPEED_SPS         4000
#define REC_X_SPEED_SPS       4000
#define REC_Z_SPEED_SPS       2000

// Motor current (mA RMS)
#define FEED_CURRENT_MA       600
#define SEL_CURRENT_MA        800
#define REC_X_CURRENT_MA      800
#define REC_Z_CURRENT_MA      600

// ------------------------------------------------------------
// Timing constants
// ------------------------------------------------------------

// Expected transit: feed_exit to post_singulation
#define EXPECTED_TRANSIT_MS   ((unsigned long)((SENSOR_SPACING_MM / FEED_SPEED_MMS) * 1000.0))

// Card pass time at a single sensor
#define CARD_PASS_TIME_MS     ((unsigned long)((CARD_LENGTH_MM / FEED_SPEED_MMS) * 1000.0))
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

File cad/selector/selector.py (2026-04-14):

# Selector module — linear carriage that routes singulated cards to 8 bins.
# Requires: pip install build123d
#
# Architecture: A NEMA17 stepper drives a GT2 belt (or leadscrew) that
# positions a card-guide carriage over one of 8 bins along the X axis.
# A singulated card enters the guide channel from the feeder exit throat,
# slides down the channel, and drops through the bin's entry funnel.
#
# The carriage rides on a single MGN12H linear rail mounted parallel to
# the bin bank. Travel range covers all 8 bin positions (~570 mm bank).
#
# Parametric on: bin count, card clearance, rail geometry, belt attachment.
#
# Run standalone:  python selector.py
# Outputs:         selector.step

from __future__ import annotations

import sys
from pathlib import Path

# Allow importing shared constants when run standalone
sys.path.insert(0, str(Path(__file__).resolve().parent.parent))

from build123d import (
    BuildPart,
    Box,
    Cylinder,
    Location,
    Align,
    Axis,
    Mode,
    Plane,
    export_step,
    export_stl,
    Pos,
    Rot,
    chamfer,
    fillet,
)
import build123d as bd

from constants import (
    CARD_WIDTH,
    CARD_HEIGHT,
    CARD_THICKNESS,
    CARD_CLEARANCE_WIDTH,
    CARD_CLEARANCE_HEIGHT,
    BIN_COUNT,
    BIN_WALL_THICKNESS,
    BIN_SPACING,
    BIN_INTERNAL_HEIGHT,
    BIN_FLOOR_THICKNESS,
    BIN_ENTRY_FUNNEL_CHAMFER,
    NEMA17_FACE,
    NEMA17_HOLE_SPACING,
    NEMA17_HOLE_DIAMETER,
    NEMA17_PILOT_DIAMETER,
    NEMA17_PILOT_DEPTH,
    NEMA17_SHAFT_DIAMETER,
    PRINT_TOL_DEFAULT,
    PRINT_TOL_TIGHT,
    M3_CLEARANCE_HOLE,
    M3_HEATSET_BORE,
    M3_HEATSET_LENGTH,
)

# ---------------------------------------------------------------------------
# Selector parameters
# ---------------------------------------------------------------------------

# MGN12H linear rail reference dimensions
RAIL_WIDTH = 12.0                # mm — rail extrusion width
RAIL_HEIGHT = 8.0                # mm — rail extrusion height
MGN12H_BLOCK_WIDTH = 27.0       # mm — carriage block width
MGN12H_BLOCK_LENGTH = 39.8      # mm — carriage block length along rail
MGN12H_BLOCK_HEIGHT = 13.0      # mm — carriage block height (above rail)
MGN12H_HOLE_SPACING_X = 20.0    # mm — mounting hole spacing along rail
MGN12H_HOLE_SPACING_Y = 12.0    # mm — mounting hole spacing across rail (given as 27 between outer, but actual M3 pattern is 12mm across for MGN12H... we use the spec)
MGN12H_MOUNT_HOLE_DIA = 3.0     # mm — M3 mounting holes

# Card guide channel dimensions
GUIDE_WALL = 2.5                 # mm — guide channel wall thickness
GUIDE_CARD_CLEARANCE = 1.0      # mm per side — clearance around card in guide
GUIDE_ENTRY_FLARE = 3.0         # mm — flared opening at top for card entry

# Guide internal dimensions (card slides through in portrait orientation)
GUIDE_INT_WIDTH = CARD_WIDTH + 2 * GUIDE_CARD_CLEARANCE    # ~65.5 mm
GUIDE_INT_DEPTH = CARD_THICKNESS + 1.0                     # ~1.3 mm — sized for one card with clearance
GUIDE_HEIGHT = 30.0             # mm — vertical extent of card guide channel

# Carriage body
CARRIAGE_WALL = 4.0             # mm — structural wall thickness
CARRIAGE_LENGTH = 50.0          # mm — along X (rail direction), must clear one bin cell
CARRIAGE_DEPTH = GUIDE_INT_WIDTH + 2 * GUIDE_WALL + 2 * CARRIAGE_WALL  # mm — along Y
CARRIAGE_HEIGHT = 12.0          # mm — base plate height (above rail block)

# Belt attachment
BELT_CLAMP_WIDTH = 12.0         # mm
BELT_CLAMP_HEIGHT = 8.0         # mm
BELT_CLAMP_DEPTH = 20.0         # mm
BELT_SLOT_WIDTH = 7.0           # mm — GT2 6mm belt + clearance
BELT_SLOT_HEIGHT = 2.0          # mm — belt thickness + clearance

# Motor mount plate
MOTOR_MOUNT_THICKNESS = 5.0     # mm
MOTOR_MOUNT_STANDOFF = 10.0     # mm — clearance between motor face and rail end

# Bin bank geometry (derived, for travel calculation)
BIN_CELL_WIDTH = CARD_WIDTH + 2 * CARD_CLEARANCE_WIDTH + 2 * BIN_WALL_THICKNESS  # 69.5 mm
BIN_PITCH = BIN_CELL_WIDTH + BIN_SPACING  # 71.5 mm center-to-center
BANK_TOTAL_WIDTH = BIN_COUNT * BIN_CELL_WIDTH + (BIN_COUNT - 1) * BIN_SPACING  # 570 mm
SELECTOR_TRAVEL = (BIN_COUNT - 1) * BIN_PITCH  # ~500.5 mm — carriage travel from bin 0 to bin 7

# Rail length (travel + carriage length + motor mount clearance at each end)
RAIL_LENGTH = SELECTOR_TRAVEL + CARRIAGE_LENGTH + 2 * MOTOR_MOUNT_STANDOFF
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

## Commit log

2026-04-12 Initial commit: shuffler V1 design, Tier 0 sim, bakeoff protocol, CAD scaffold, rig firmware
    Tier 0 sim validates 2-pass 8-bin FIFO at ~9.2 riffle equivalents (target: 7).
    Architecture premises P1-P3 locked. Feeder bakeoff protocol ready for rig build.
    Build123d parametric CAD scaffolding for bin bank (complete) and feeder (skeleton).
    ESP32 bakeoff rig firmware with interrupt-driven dual-sensor event classification.
2026-04-13 Add full CAD modules, main firmware, and datum/tolerance budget
    CAD: selector (belt-driven carriage on MGN12H), recombine (pusher/elevator
    + accumulator tray), output tray (spring backstop + funnel entry). All
    parametric Build123d, export_all.py now wires all five modules.
    Firmware: 13-state machine with per-pass count invariants, TMC2209 UART
    motor control (4 axes), 6 ISR-driven sensors, NVS brownout recovery,
    SSD1306 OLED display, and serial service mode. 1,942 lines.
    Datum budget: 5 interface stackups analyzed worst-case. Critical findings:
    bin-to-recombine pickup needs compliant approach (variable 1-10 card stacks),
    recombine-to-feeder reload needs squaring step (0.1mm margin at worst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
    [config.h, main.cpp, motors.cpp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]
2026-04-13 Add chassis, BOM, friction+retard feeder, and recombine datum fixes
    Chassis: 783x140mm base plate split into 3 printable sections (~261mm each),
    datum rails (A/B/C), slotted mounting holes per tolerance budget, electronics
    bay with ESP32+TMC2209 standoffs, cable routing channels.
    BOM: ~$300 total against $500 ceiling. Full parts list with quantities,
    specs, and sourcing for electronics, mechanical, and fasteners.
    Feeder Candidate A: friction roller + retard pad singulation geometry with
    625ZZ bearing pockets, eccentric bushing for nip adjustment, spring-loaded
    retard pad on dovetail slide, exit guide channel.
    Recombine fixes for datum budget findings: sensor-guided Z pusher with
    flex-zone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
    [recombine.py]
2026-04-13 Add wiring reference, print guide, and assembly sequence
    Wiring: master GPIO pinout, TMC2209 UART bus map, power distribution
    diagram, connector specs, cable routing with EMI separation rules.
    Print guide: 21 parts with orientation, layer height, infill, support,
    critical dimensions, post-processing. Splitting strategy for oversized
    parts (bin bank into 4 quarters, chassis into 3 sections).
    Assembly: 12-phase build sequence from chassis frame through calibration.
    Includes nip gap adjustment procedure, belt tensioning, sensor placement,
    firmware flash, first power-on self-test, and bin position calibration.
2026-04-13 Add landing page, market research, and 3D render pipeline
    Landing page: dark poker-table theme, 10 sections (hero, problem,
    product cards, how-it-works, specs, social proof, comparison table,
    FAQ, waitlist form, footer). Single HTML file, responsive, CSS-only
    animations. Product positioned as ShuffleDeck Core ($500) + RFID
    add-on ($300) + Stream overlay (free/open-source).
    Market research: validated that no integrated consumer smart poker
    table kit exists. RFID poker cards commercially available (Faded Spade,
    13.56MHz). Gap between $60 Amazon junk and $5,000+ custom builds.
    Target: serious home game hosts and poker streamers.
    Render setup: Build123d assembly script exports positioned STEP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
2026-04-13 Add RFID reader, streaming overlay, 3D renders, and interactive landing page
    RFID reader firmware (firmware/rfid-reader/): ESP32 + RC522, NVS-backed
    card registration, WebSocket broadcast of card events as JSON. Registration
    mode for learning Faded Spade RFID UIDs, read mode for live scanning.
    AP mode fallback when no WiFi configured.
    Streaming overlay (site/overlay.html): OBS-compatible browser source,
    9-seat poker table layout, CSS-only card graphics with flip animations,
    configurable reveal delay for anti-cheat, demo mode without hardware.
    Connects to RFID reader via WebSocket.
    3D renders: GLTF (.glb) exports of all modules + full assembly for
    browser-based three.js viewing. STEP export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
    [assembly_exploded.step, assembly_full.step, bin_bank_detail.step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]
2026-04-13 Add README, fix GitHub links, wire waitlist form
    README with project overview, architecture summary, quick start,
    build instructions, and validation results table.
    Landing page: GitHub links point to gmackie/shuffledeck, waitlist
    form wired to Formspree with async submit and success feedback.
2026-04-13 Move assembly GLB into site/ for GitHub Pages compatibility
    The 3D viewer needs the model served from the same directory as the
    HTML. Copy assembly.glb to site/ and update the loader path.
2026-04-13 Add build-prep docs, CAD exports, and firmware serial commands
    Motor setup guide for salvaged Lumen 3D printer NEMA17s, RFID
    through-felt validation protocol ($19 experiment), and first
    power-on preflight checklist. Firmware now supports status,
    selftest, sensors, shuffle, and service commands from any state.
    Includes all STL + STEP exports from export_all.py.
    [bin_bank.step, bin_bank.stl, chassis_full.step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]
2026-04-13 Add consolidated order list with Amazon search terms
    Organized by order for fastest checkout. ~$269 total out of
    pocket after subtracting parts already on hand (Lumen motors,
    ESP32, TMC2209 drivers). Linear rails on AliExpress, everything
    else from Amazon for 1-2 day delivery.
2026-04-14 Fix assembly.glb to be actual binary GLB format
    Was exporting as JSON glTF with .glb extension, which three.js
    couldn't parse. Re-exported with binary=True flag.
2026-04-14 Fix 3D viewer to auto-fit camera to model bounding box
    Build123d exports mm as meters in GLTF, so the model was ~1m
    wide but the camera was 900 units away. Now computes bounding
    box on load and positions camera automatically.
2026-04-14 Add hardware models, colored assembly, and auto-fit 3D viewer
    New cad/hardware.py: visual NEMA17 motor, MGN12H rail+carriage,
    GT2 pulleys, belt segments, bearings. New cad/render_hero.py
    assembles 20 parts (printed + hardware) with correct positioning:
    selector rail above bins, recombine behind, motors at rail ends.
    Viewer now colorizes by part: emerald for printed parts, steel
    for rails, near-black for motors, orange for belts, silver for
    pulleys. Camera auto-fits to bounding box on load.
2026-04-14 Rewrite 3D model with baked PBR materials and proper assembly
    Colors are now baked directly into the GLTF materials via GLB
    post-processing (no more JS-side color assignment). 16 parts
    with distinct materials: emerald for printed parts, steel for
    rails, dark gray for motors, orange for belts.
    Assembly positioning fixed: parts placed using actual bounding
    box origins. Selector rail above bins, recombine behind bins,
    motors at rail ends, feeder motor below hopper.
2026-04-14 Redesign hero model for visual clarity over dimensional accuracy
    Replaced engineering-accurate assembly with stylized marketing
    model. Bins are taller (40mm vs 22mm) so they read as card slots.
    Feeder hopper has visible cavity. Removed the 783mm chassis that
    dominated the view. Selector carriage has a card guide tower.
    Motors, rails, and orange belts provide "real machine" context.
    193KB GLB, 14 colored parts.
2026-04-14 Fix CAD exports and refresh deployed hero model
    [assembly_exploded.step, assembly_full.step, bin_bank.step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]
